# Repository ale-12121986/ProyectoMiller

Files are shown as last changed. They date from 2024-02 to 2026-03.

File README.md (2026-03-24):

## 🏭 Sistema de Automatización para Máquinas de Flexografía
📌 Descripción del Proyecto

Este proyecto consiste en el diseño y desarrollo de un sistema de automatización industrial aplicado a máquinas de impresión flexográfica.

Se implementó una arquitectura distribuida basada en microcontroladores, donde un nodo maestro coordina múltiples nodos esclavos a través de comunicación I2C, permitiendo el control independiente de cada cuerpo de impresión.

El sistema está orientado a mejorar la precisión de registro, facilitar la operación manual y garantizar la persistencia de configuraciones críticas del proceso.

## 🎯 Objetivos
Automatizar el control de múltiples cuerpos de impresión.
Mejorar la precisión en el registro de impresión.
Implementar una arquitectura escalable y robusta.
Garantizar almacenamiento persistente de parámetros operativos.
Facilitar la operación mediante interfaz manual con feedback visual.
⚙️ Arquitectura del Sistema

## El sistema se basa en un modelo Maestro–Esclavo:

Maestro (Arduino Mega 2560)
Control central del sistema
Gestión de comunicación I2C
Coordinación de los cuerpos de impresión
Esclavos (nodos independientes)
Control individual de cada cuerpo de impresión
Recepción de comandos del maestro
Ejecución de ajustes de registro
Comunicación
Protocolo: I2C (Wire Library)
Topología multi-dispositivo

## 🧠 Funcionalidades Principales
🔹 Control de Cuerpos de Impresión
Manejo independiente de hasta 6 cuerpos de impresión
Ajustes precisos en tiempo real
🔹 Control de Registro
Registro circunferencial
Registro lateral
Mejora de alineación en impresión
🔹 Persistencia de Datos
Uso de EEPROM para almacenamiento de:
Configuraciones
Parámetros de calibración
🔹 Interfaz de Usuario
Operación manual
Feedback visual para el operador
Control directo sin necesidad de sistemas externos
🔹 Hardware Personalizado

## Diseño de PCB propio
Circuitos de multiplexación optimizados

## 🧪 Tecnologías Utilizadas
Arduino Mega 2560
Comunicación I2C (Wire Library)
EEPROM
Diseño de PCB
Sistemas Embebidos
Automatización Industrial

## 🏗️ Estructura del Proyecto
/src
  ├── master/
  │     ├── main.ino
  │     └── i2c_manager.h
  │
  ├── slave/
  │     ├── slave_controller.ino
  │     └── register_control.h
  │
  ├── drivers/
  │     ├── eeprom_manager.h
  │     └── io_control.h
  │
  └── ui/
        └── manual_interface.h

/hardware
  ├── pcb_design/
  └── schematics/

/docs
  ├── architecture.md
  └── wiring_diagram.png

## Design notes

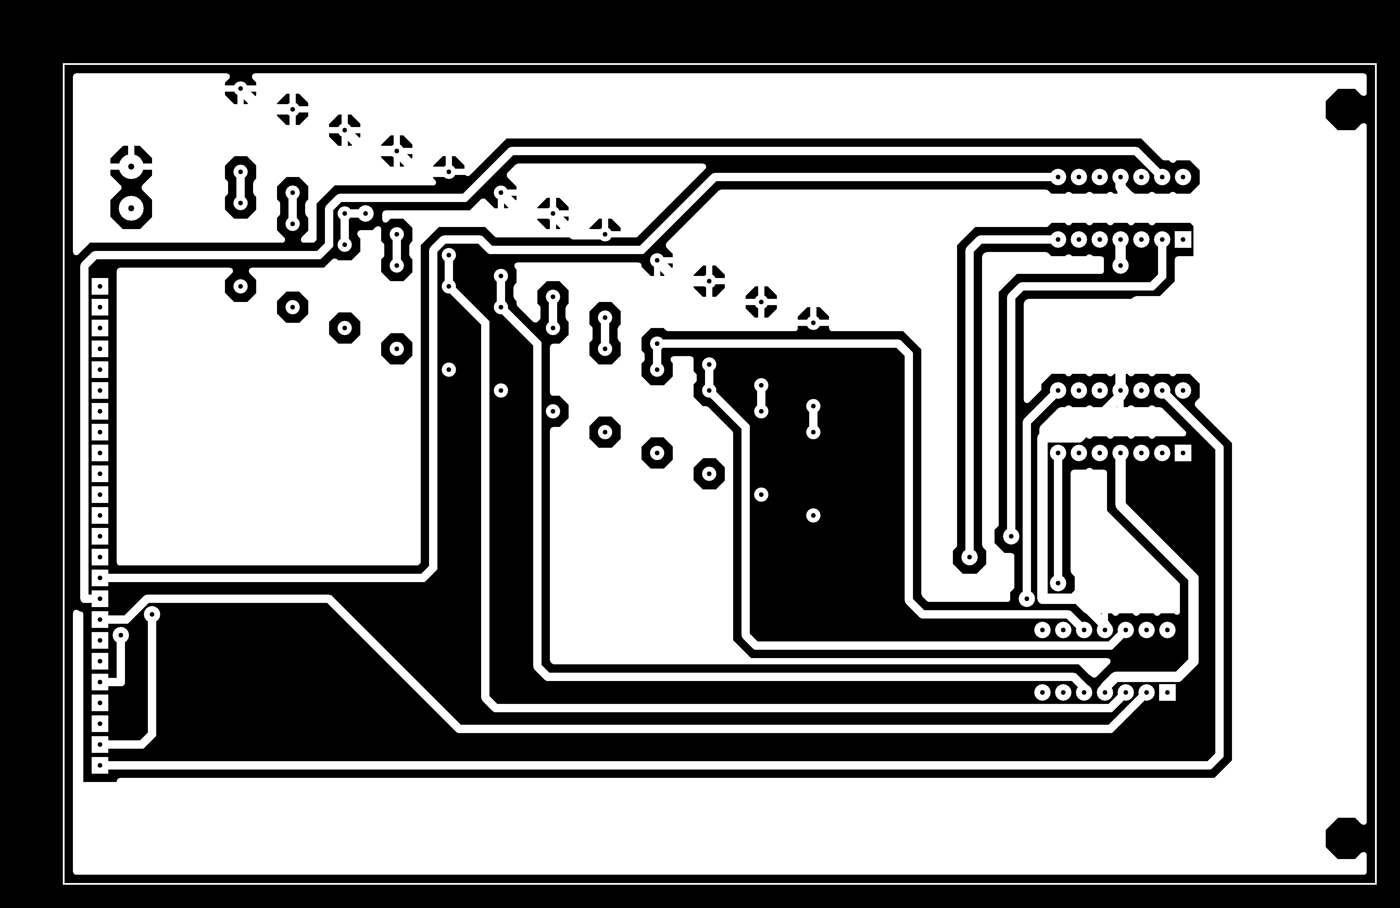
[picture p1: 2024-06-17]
pcb/PlacaBottonRegulador.bmp

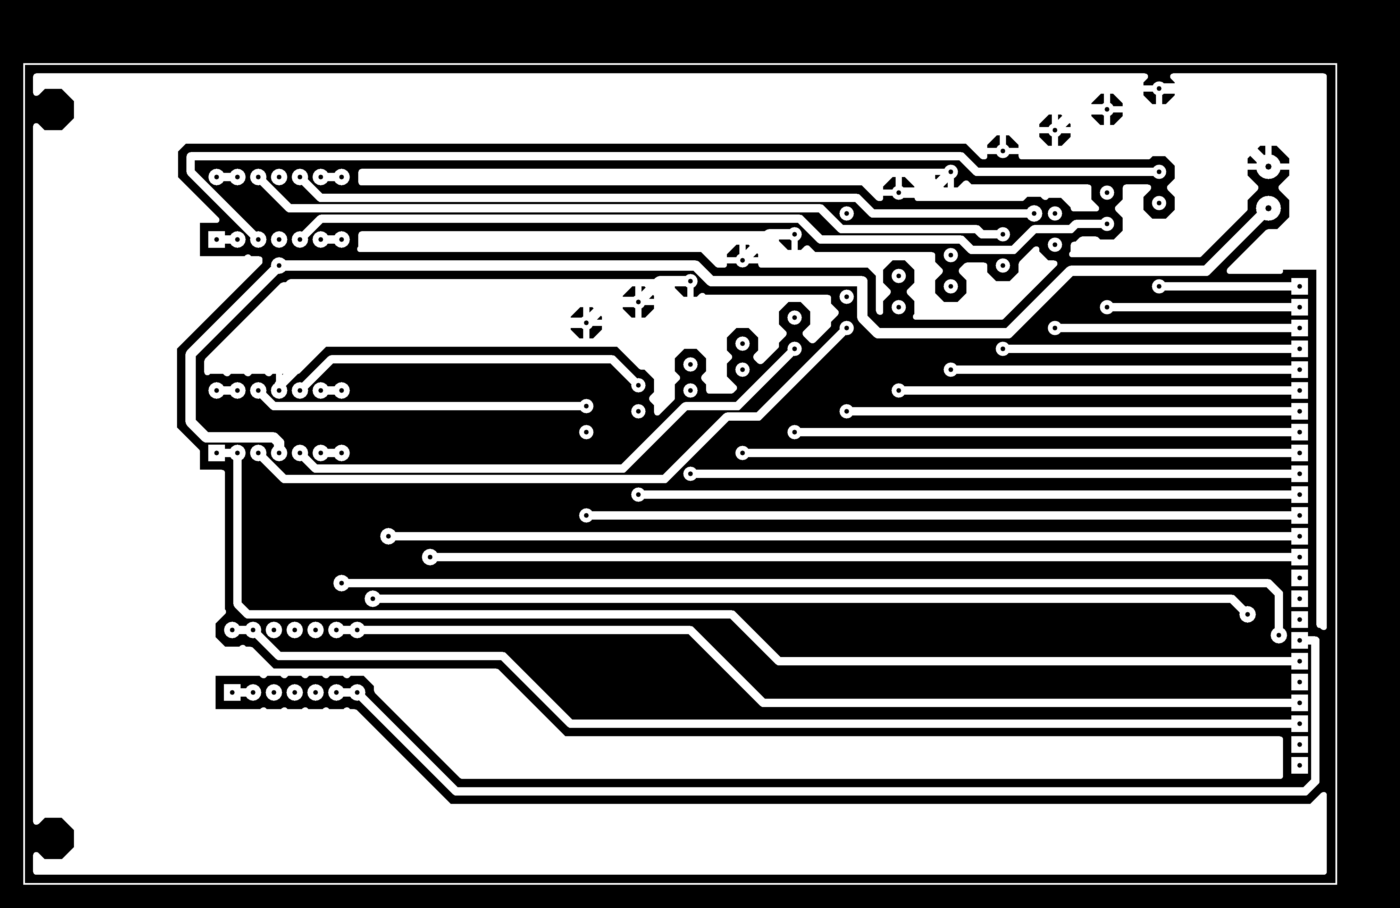
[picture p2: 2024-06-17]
pcb/PlacaTopRegulador.bmp

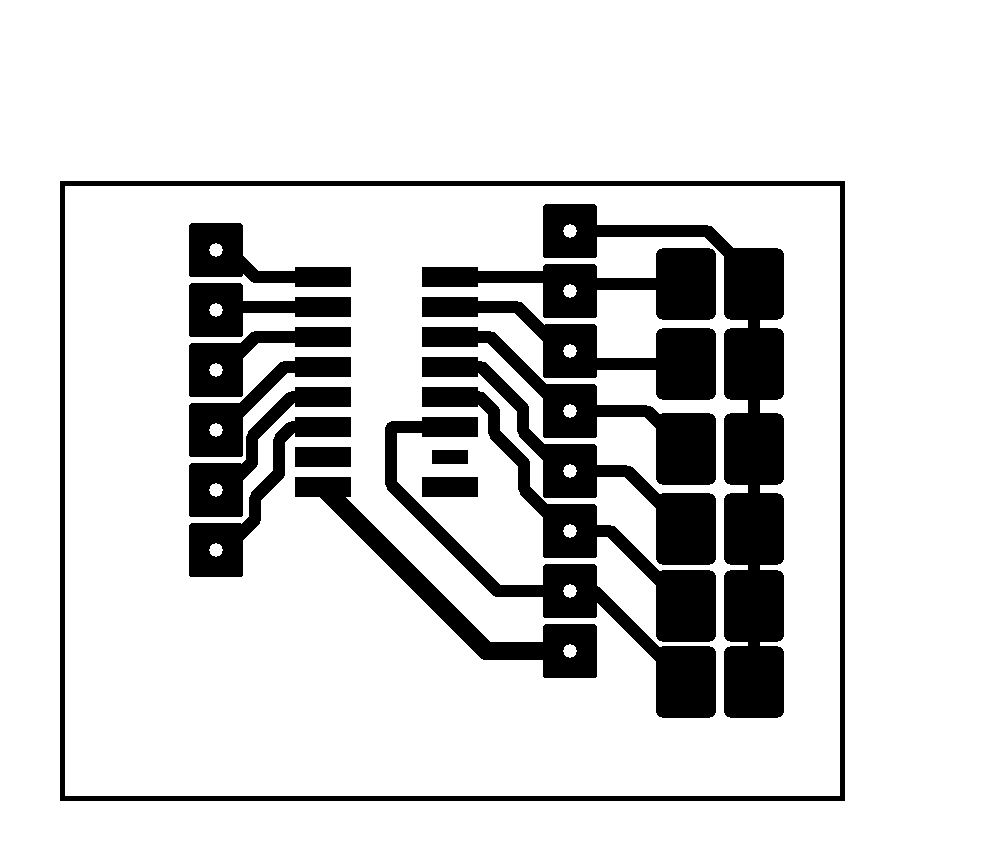
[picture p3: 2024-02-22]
pcb/driver miller.BMP

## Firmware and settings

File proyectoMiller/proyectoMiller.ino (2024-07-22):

//Maestro
#include "ControlClavija.h"
#include "DatosDisplay.h"
#include "Iluminacion.h"
#include "Direcciones.h"
#include "Registro.h"
#include "EEPROM.h"
#include <Wire.h>
#include "WString.h"
int direccionBotones = 7;
int placaClavija1, placaClavija2, placaClavija3, placaClavija4;
int clavijas = 0, cuerpos = 0, cuerpoViejo = 0, leerPotenciometro, cuerpoViejo2 = 0;
float valor1;
String valorRegistro;
int datoBarra;
int conteo = 0;
int dirBarra1 = 0, dirBarra2 = 0, dirBarra3 = 0, dirBarra4 = 0;
boolean memoria = false, trabajo = false;
int valorTinteros[6][28];
int matricesCuerpos[6][28];
const byte Boton1 = 23;  // cuerpo anterior 22
const byte Boton2 = 28;  // cuerpo1 29
const byte Boton3 = 29;  // cuerpo2 28
const byte Boton4 = 27;  // cuerpo3  26
const byte Boton5 = 22;  // cuerpo4
const byte Boton6 = 26;  // cuerpo5  27
const byte Boton7 = 24;  // cuerpo6  25
const byte Boton8 = 25;  // selecciono cambiar 24
const int pot = A2;
const int pot2 = A1;
int Centena, Decena, Unidad;
int envios = 3;
//Se llama las clases
DatosDisplay datosDisplay;
ControlClavija controlarClavija;
Direcciones direccionControl;
Iluminacion iluminacion;
Registro registro;

int ejecucionDeClavija(int posicion) {
  valor1 = analogRead(pot);
  delay(100);
  leerDato(valor1);
  Serial.println(valor1);
  datosDisplay.enviarDato(Decena, Centena, posicion);
  return valor1;
}
void enviarDatoBarra(int dato){
conteo++;
  if(conteo == 20){
    //Serial.println("se envia el dato a la barra");
    conteo = 0;
    registro.ValorBarra(dato);
    //registro.ValorBarra(dato);
  }
}
void moverRegistroC(int valor){
  retardo10ms();
  registro.moverRegistroCircunferencial(valor);
  retardo10ms();
  registro.moverRegistroCircunferencial(valor);
}

void moverRegistroL(int valor){
  retardo10ms();
  registro.moverRegistroLateral(valor);
}
void moverRegistroBarra(int valor){
  retardo10ms();
  registro.BarridoTinta(valor);
}
void cambiarCuerpo(int cuerpo){
  retardo10ms();
  registro.activarCuerpos(cuerpos);
}
void leerDato(float Valor) {
  int valor;
  valor = map(Valor, 0, 1024, 0, 1000);
  //valor = (Valor * 1000) / 1024;
  Centena = valor / 100;
  Decena = (valor - Centena * 100) / 10;
  Unidad = (valor - Centena * 100 - Decena * 10);
  datoBarra = Centena * 10 + Decena;

}
void ejecucionRegistro(String dato){  
  int negativo = 0;
  int valor = dato.toInt();
  valor = map(valor,0,1023,-150, 150);
  Centena = valor/100;
  //Decena = valor/10;
  Decena = (valor - Centena*100)/10;
  Unidad = (valor - Centena*100 - Decena*10);
  if (valor < 0) {
    negativo = 8;
    Centena = Centena*-1;
    Decena = Decena *-1;
    Unidad = Unidad *-1;    
  }
  datosDisplay.enviarDato(Unidad, Decena,1);
  retardo10ms();
  datosDisplay.enviarDato(Centena, negativo,2);
}

void barridoCuerpo(int cuerpos) {  //barre todos los cuerpos de las calvija e imprime todos los datos en los display
  //controlarClavija.posInicial();
  int i = 1;
  do {
    direccionesDeBotones();
    //Serial.print("leyendo clavija");
    //Serial.println(i);
    controlarClavija.leerPotIzquierdo(cuerpos, i);
    retardo100ms();
    leerPotenciometro = ejecucionDeClavija(4);  //va a la rutina de escribir en los display y trae el valor del potenciometro
    controlarClavija.leerPotderecho(cuerpos, i);
    retardo100ms();
    i++;
    leerPotenciometro = ejecucionDeClavija(3);
    controlarClavija.leerPotIzquierdo(cuerpos, i);
    retardo100ms();
    leerPotenciometro = ejecucionDeClavija(2);
    controlarClavija.leerPotderecho(cuerpos, i);
    retardo100ms();
    leerPotenciometro = ejecucionDeClavija(1);
    i++;
  } while (i <= 14);
}
void guardarMemoria(int cuerpos) {  //Se guarda en memoria el valor de todos los potenciometros de cada cuerpo
  int8_t dirMemoria = 0;
  for (int i = 1; i <= 14; i++) {
    controlarClavija.leerPotIzquierdo(cuerpos, i);
    retardo100ms();
    valor1 = analogRead(pot);
    EEPROM.put(dirMemoria, valor1);
    dirMemoria++;
    controlarClavija.leerPotderecho(cuerpos, i);
    retardo100ms();
    valor1 = analogRead(pot);
    EEPROM.put(dirMemoria, valor1);
    dirMemoria++;
  }
}

void compararValoresCuerpos(int cuerpos) {
  int valorPot = 0, valorMemoria = 0, dirMemoria = 0;
  for (int i = 1; i <= 14; i++) {
    EEPROM.get(dirMemoria, valorMemoria);
    controlarClavija.leerPotIzquierdo(cuerpos, i);
    retardo100ms();
    valorPot = analogRead(pot);
    while (valorPot < valorMemoria) {
      controlarClavija.motorIzquierdoMas(cuerpos, i);
    }
    while (valorPot > valorMemoria) {
      controlarClavija.motorIzquierdoMenos(cuerpos, i);
    }
    dirMemoria++;
    EEPROM.get(dirMemoria, valorMemoria);
    controlarClavija.leerPotderecho(cuerpos, i);
    retardo100ms();
    valorPot = analogRead(pot);
    while (valorPot < valorMemoria) {
      controlarClavija.motorDerechoMas(cuerpos, i);
    }
    while (valorPot > valorMemoria) {
      controlarClavija.motorDerechoMenos(cuerpos, i);
    }
    dirMemoria++;
  }
}

void direccionesDeBotones() {
  direccionBotones += 1;
  if (direccionBotones == 15) {
    direccionBotones = 8;
  }
  //Serial.print("LK");
  //Serial.println(direccionBotones);
  switch (direccionBotones) {
    case 14:
      placaClavija1 = 2;
      placaClavija2 = 2;
      placaClavija3 = 1;
      placaClavija4 = 1;
      dirBarra1 = 1;
      dirBarra2 = 2;
      dirBarra3 = 3;
      dirBarra4 = 4;
      break;
    case 13:
      placaClavija1 = 4;
      placaClavija2 = 4;
      placaClavija3 = 3;
      placaClavija4 = 3;
      dirBarra1 = 5;
      dirBarra2 = 6;
      dirBarra3 = 7;
      dirBarra4 = 8;
      break;
    case 12:
      placaClavija1 = 6;
      placaClavija2 = 6;
      placaClavija3 = 5;
      placaClavija4 = 5;
      dirBarra1 = 9;
      dirBarra2 = 10;
      dirBarra3 = 11;
      dirBarra4 = 12;
      break;
    case 11:
      placaClavija1 = 8;
      placaClavija2 = 8;
      placaClavija3 = 7;
      placaClavija4 = 7;
      dirBarra1 = 13;
      dirBarra2 = 14;
      dirBarra3 = 15;
      dirBarra4 = 16;
      break;
    case 10:
      placaClavija1 = 10;
      placaClavija2 = 10;
      placaClavija3 = 9;
      placaClavija4 = 9;
      dirBarra1 = 17;
      dirBarra2 = 18;
      dirBarra3 = 19;
      dirBarra4 = 20;
      break;
    case 9:
      placaClavija1 = 12;
      placaClavija2 = 12;
      placaClavija3 = 11;
      placaClavija4 = 11;
      dirBarra1 = 21;
      dirBarra2 = 22;
      dirBarra3 = 23;
      dirBarra4 = 24;
      break;
    case 8:
      placaClavija1 = 14;
      placaClavija2 = 14;
      placaClavija3 = 13;
      placaClavija4 = 13;
      dirBarra1 = 25;
      dirBarra2 = 26;
      dirBarra3 = 27;
      dirBarra4 = 28;
      break;
    default:
      break;
  }
  direccionControl.imprimirDireccion(direccionBotones);
}
void retardo50ms() {
  delay(50);
}
void retardo300ms() {
  delay(300);
}
void retardo10ms() {
  delay(10);
}
void retardo100ms() {
  delay(100);
}
void setup() {
  controlarClavija.configurar();
  datosDisplay.configurar();
  direccionControl.configurar();
  iluminacion.configurar();
  registro.Configurar();
  pinMode(Boton1, INPUT);
  pinMode(Boton2, INPUT);
  pinMode(Boton3, INPUT);
  pinMode(Boton4, INPUT);
  pinMode(Boton5, INPUT);
  pinMode(Boton6, INPUT);
  pinMode(Boton7, INPUT);
  pinMode(Boton8, INPUT);
  pinMode(pot, INPUT);
  //pinMode(poteDerecho,INPUT);
  //analogReference(DEFAULT);

  Serial.begin(115200);
  iluminacion.trabajoMemoria(0);
  iluminacion.encenderCuerpo(0);
  //Serial.println("Inicio Imprenta miller");
  controlarClavija.posInicial();
  delay(1000);
}
void loop() {
  // put your main code here, to run repeatedly:

Inicio:
  direccionControl.imprimirDireccion(6);  //direccion de lk6  seleccion de M1/M2
  retardo10ms();

  while (true) {  //M1: trabajo M2: memoria
    while (digitalRead(Boton6) == LOW && digitalRead(Boton7) == LOW) {
    retardo10ms();
    }
    if (digitalRead(Boton6) == HIGH) {  // Boton M1
      while (digitalRead(Boton6) == HIGH) {
        retardo10ms();
        //Serial.println("Se preciono M1 y se va a trabajo");
      }
      memoria = false;
      trabajo = true;
      iluminacion.trabajoMemoria(1);
      //Serial.println("Se preciono M1 y se va a trabajo");
      retardo300ms();
      goto Trabajar;
    }
    
    if (digitalRead(Boton7) == HIGH) {  // Boton M2
      while (digitalRead(Boton7) == HIGH) {
        retardo50ms();
      }
      trabajo = false;
      memoria = true;
      iluminacion.trabajoMemoria(2);
      //Serial.println("Se preciono M2 y se va a memoria");
      //goto Memoria;
      goto Trabajar;
    }
  }
Trabajar:
  direccionControl.imprimirDireccion(4);
  while (digitalRead(Boton1) == LOW && digitalRead(Boton2) == LOW && digitalRead(Boton3) == LOW && digitalRead(Boton4) == LOW && digitalRead(Boton5) == LOW && digitalRead(Boton6) == LOW && digitalRead(Boton7) == LOW && digitalRead(Boton8) == LOW) {
    retardo50ms();
  }
trabajoCuerpo:
  direccionControl.imprimirDireccion(4);
  //direccionControl.imprimirDireccion(4);// Direccion de las placas de seleccionar cuerpo
  if (digitalRead(Boton1) == HIGH) {
    iluminacion.encenderCuerpo(7);
    //Serial.println("Se selecciono el cuerpo anterior");
    cuerpoViejo2 = cuerpos;
    cuerpos = cuerpoViejo;
    iluminacion.encenderCuerpo(cuerpos);
    registro.activarCuerpos(cuerpos);
    while (digitalRead(Boton1) == HIGH) {
      retardo100ms();
    }
    iluminacion.encenderCuerpo(9);
    //registro.activarCuerpos(cuerpos);
    cuerpoViejo = cuerpoViejo2;
    if (trabajo == true) {
      barridoCuerpo(cuerpos);
    }
  }

  if (digitalRead(Boton2) == HIGH) {
    //Serial.println("Se selecciono el cuerpo1");
    cuerpoViejo = cuerpos;
    cuerpos = 1;
    //registro.activarCuerpos(cuerpos);
    iluminacion.encenderCuerpo(cuerpos);
    while (digitalRead(Boton2) == HIGH) {
      retardo100ms();
    }
    cambiarCuerpo(cuerpos);
    iluminacion.encenderCuerpo(cuerpos);
    if (trabajo == true) {
      barridoCuerpo(cuerpos);
    }

  } else if (digitalRead(Boton3) == HIGH) {
    //Serial.println("Se selecciono el cuerpo2");
    cuerpoViejo = cuerpos;
    cuerpos = 2;
    //registro.activarCuerpos(cuerpos);
    iluminacion.encenderCuerpo(cuerpos);
    while (digitalRead(Boton3) == HIGH) {
      retardo100ms();
    }
    cambiarCuerpo(cuerpos);
    iluminacion.encenderCuerpo(cuerpos);
    if (trabajo == true) {
      barridoCuerpo(cuerpos);
    }

  } else if (digitalRead(Boton4) == HIGH) {
    //Serial.println("Se selecciono el cuerpo3");
    cuerpoViejo = cuerpos;
    cuerpos = 3;
    iluminacion.encenderCuerpo(cuerpos);
    while (digitalRead(Boton4) == HIGH) {
      retardo100ms();
    }
    cambiarCuerpo(cuerpos);
    iluminacion.encenderCuerpo(cuerpos);
    if (trabajo == true) {
      barridoCuerpo(cuerpos);
    }

  } else if (digitalRead(Boton5) == HIGH) {
    //Serial.println("Se selecciono el cuerpo4");
    cuerpoViejo = cuerpos;
    cuerpos = 4;
    iluminacion.encenderCuerpo(cuerpos);
    while (digitalRead(Boton5) == HIGH) {
      retardo100ms();
    }
    cambiarCuerpo(cuerpos);
    iluminacion.encenderCuerpo(cuerpos);
    if (trabajo == true) {
      barridoCuerpo(cuerpos);
    }

  } else if (digitalRead(Boton6) == HIGH) {
    //Serial.println("Se selecciono el cuerpo5");
    cuerpoViejo = cuerpos;
    cuerpos = 5;
    iluminacion.encenderCuerpo(cuerpos);
    while (digitalRead(Boton6) == HIGH) {
      retardo100ms();
    }
    cambiarCuerpo(cuerpos);
    iluminacion.encenderCuerpo(cuerpos);
    barridoCuerpo(cuerpos);

  } else if (digitalRead(Boton7) == HIGH) {
    cuerpoViejo = cuerpos;
    cuerpos = 6;
    iluminacion.encenderCuerpo(cuerpos);
    //Serial.println("Se selecciono el cuerpo6");
    while (digitalRead(Boton7) == HIGH) {
      retardo100ms();
    }
    cambiarCuerpo(cuerpos);
    iluminacion.encenderCuerpo(cuerpos);
    if (trabajo == true) {
      barridoCuerpo(cuerpos);
    }
    if(memoria == true ){
      barridoCuerpo(cuerpos);
      goto Memoria;
    }
  } else if (digitalRead(Boton8) == HIGH) {
    //cuerpos = 90;
    //posCuerpo = 6;
    //Serial.println("Se selecciono cambiar");
    while (digitalRead(Boton8) == HIGH) {
      retardo100ms();
      
    }
    //goto Inicio;
  }
  if (trabajo == true) {
    goto Tinteros;
  }
Tinteros:
  direccionesDeBotones();  // direcciones de las clavijas
  delay(20);

  if (digitalRead(Boton7) == HIGH) {  //motor izquierdo que gira derecha
    controlarClavija.posInicial();
    direccionControl.imprimirLaDireccion();
    Serial.println("Boton 7(Boton izquierdo +)");
    controlarClavija.motorIzquierdoMenos(cuerpos, placaClavija1);
    for (int i = 0; i < 2; i++) {
      //registro.DireccionBarra(dirBarra1);
    }
    while (digitalRead(Boton7) == HIGH) {
      
      leerPotenciometro = ejecucionDeClavija(4);  //va a la rutina de escribir en los display y trae el valor del potenciometro
      //enviarDatoBarra(datoBarra);
      if (leerPotenciometro >= 900) {
        controlarClavija.resetflipflop();
      }
    }
    controlarClavija.resetflipflop();
    retardo10ms();
  }

  if (digitalRead(Boton1) == HIGH) {  //motor izquierdo que gira izquierda
    controlarClavija.posInicial();
    direccionControl.imprimirLaDireccion();
    Serial.println("Boton 1(Boton izquierdo -)");
    controlarClavija.motorIzquierdoMas(cuerpos, placaClavija1);
    for (int i = 0; i < 2; i++) {
      //registro.DireccionBarra(dirBarra1);
    }
    while (digitalRead(Boton1) == HIGH) {
      
      leerPotenciometro = ejecucionDeClavija(4);  //va a la rutina de escribir en los display y trae el valor del potenciometro
      //enviarDatoBarra(datoBarra);
      if (leerPotenciometro <= 100) {
        controlarClavija.resetflipflop();
      }
    }
    controlarClavija.resetflipflop();
    retardo10ms();
  }

  if (digitalRead(Boton2) == HIGH) {  //motor derecho que gira derecha
    controlarClavija.posInicial();
    direccionControl.imprimirLaDireccion();
    Serial.println("Boton 2(Boton Boton Derecho +)");
    controlarClavija.motorDerechoMenos(cuerpos, placaClavija2);
    for (int i = 0; i < 2; i++) {
      //registro.DireccionBarra(dirBarra2);
    }
    while (digitalRead(Boton2) == HIGH) {
  
      leerPotenciometro = ejecucionDeClavija(3);  //va a la rutina de escribir en los display y trae el valor del potenciometro
      //enviarDatoBarra(datoBarra);
      if (leerPotenciometro >= 900) {
        controlarClavija.resetflipflop();
      }
    }
    controlarClavija.resetflipflop();
    retardo10ms();
  }

  if (digitalRead(Boton6) == HIGH) {  //motor derecho que gira izquierda
    controlarClavija.posInicial();
    direccionControl.imprimirLaDireccion();
    Serial.println("Boton 6(Boton Derecho -)");
    controlarClavija.motorDerechoMas(cuerpos, placaClavija2);
    for (int i = 0; i < 2; i++) {
      //registro.DireccionBarra(dirBarra2);
    }
    while (digitalRead(Boton6) == HIGH) {
    
      leerPotenciometro = ejecucionDeClavija(3);  //va a la rutina de escribir en los display y trae el valor del potenciometro
      //enviarDatoBarra(datoBarra);
      if (leerPotenciometro <= 100) {
        controlarClavija.resetflipflop();
      }
    }
    controlarClavija.resetflipflop();
    retardo10ms();
  }

  if (digitalRead(Boton4) == HIGH) {  //motor izquierdo que girai derecha
    controlarClavija.posInicial();
    direccionControl.imprimirLaDireccion();
    Serial.println("Boton 4(Boton izquierdo +)");
    controlarClavija.motorIzquierdoMenos(cuerpos, placaClavija3);
    for (int i = 0; i < 2; i++) {
      //registro.DireccionBarra(dirBarra3);
    }
    while (digitalRead(Boton4) == HIGH) {
      leerPotenciometro = ejecucionDeClavija(2);  //va a la rutina de escribir en los display y trae el valor del potenciometro
      //enviarDatoBarra(datoBarra);
      if (leerPotenciometro >= 900) {
        controlarClavija.resetflipflop();
      }
    }
    controlarClavija.resetflipflop();
    retardo50ms();
  }

  if (digitalRead(Boton3) == HIGH) {  //motor izquierdo que gira izquierda
    controlarClavija.posInicial();
    direccionControl.imprimirLaDireccion();
    Serial.println("Boton 3(Boton izquierdo -)");
    controlarClavija.motorIzquierdoMas(cuerpos, placaClavija3);
    for (int i = 0; i < 2; i++) {
      //registro.DireccionBarra(dirBarra3);
    }
    while (digitalRead(Boton3) == HIGH) {
      
      leerPotenciometro = ejecucionDeClavija(2);
      //enviarDatoBarra(datoBarra);
      if (leerPotenciometro <= 100) {
        controlarClavija.resetflipflop();
      }
    }
    controlarClavija.resetflipflop();
    retardo10ms();
  }

  if (digitalRead(Boton8) == HIGH) {  //motor derecho que gira derecha
    controlarClavija.posInicial();
    direccionControl.imprimirLaDireccion();
    Serial.println("Boton 8(Boton Boton Derecho +)");
    controlarClavija.motorDerechoMenos(cuerpos, placaClavija4);
    for (int i = 0; i < 2; i++) {
      //registro.DireccionBarra(dirBarra4);
    }
    while (digitalRead(Boton8) == HIGH) {
    
      leerPotenciometro = ejecucionDeClavija(1);  //va a la rutina de escribir en los display y trae el valor del potenciometro
      //enviarDatoBarra(datoBarra);
      if (leerPotenciometro >= 900) {
        controlarClavija.resetflipflop();
      }
    }
    controlarClavija.resetflipflop();
    retardo10ms();
  }

  if (digitalRead(Boton5) == HIGH) {  //motor derecho que gira izquierda
    controlarClavija.posInicial();
    direccionControl.imprimirLaDireccion();
    Serial.println("Boton 5(Boton Derecho -)");
    controlarClavija.motorDerechoMas(cuerpos, placaClavija4);
    for (int i = 0; i < 2; i++) {
      //registro.DireccionBarra(dirBarra4);
    }
    while (digitalRead(Boton5) == HIGH) {
      leerPotenciometro = ejecucionDeClavija(1);  //va a la rutina de escribir en los display y trae el valor del potenciometro
      //enviarDatoBarra(datoBarra);
      if (leerPotenciometro <= 100) {
        //Serial.print("entro en proteccion");
        controlarClavija.resetflipflop();
      }
    }
    controlarClavija.resetflipflop();
    retardo10ms();
  }
  direccionControl.imprimirDireccion(4);  //cambiar de cuerpo
  if (digitalRead(Boton1) == HIGH && digitalRead(Boton2) == HIGH && digitalRead(Boton3) == HIGH && digitalRead(Boton4) == HIGH && digitalRead(Boton5) == HIGH && digitalRead(Boton6) == HIGH && digitalRead(Boton7) == HIGH && digitalRead(Boton8) == HIGH) {
    retardo50ms();
    goto Trabajar;
    //goto trabajoCuerpo;
  }

  direccionControl.imprimirDireccion(6);  //direccion de lk6  seleccion de M1/M2
  if (digitalRead(Boton6) == HIGH || digitalRead(Boton7) == HIGH) {
    goto Inicio;
  }
  if(digitalRead(Boton2) == HIGH){    //Boton menos mutual stting module 
    //Serial.println("Boton 2(Boton Boton + mutual stting module)");
    moverRegistroBarra(2);
    while (digitalRead(Boton2) == HIGH) {
      retardo50ms();
      //leerPotenciometro = ejecucionDeClavija(2);
    }
    moverRegistroBarra(4);
  }
  if(digitalRead(Boton1) == HIGH){    //Boton menos mutual stting module 
    //Serial.println("Boton 1(Boton Boton - mutual stting module)");
    moverRegistroBarra(3);
    while (digitalRead(Boton1) == HIGH) {
      retardo50ms();
      //leerPotenciometro = ejecucionDeClavija(2);
    }
    moverRegistroBarra(4);
  }

  //---------------Registro circunferencial-------------------------
  direccionControl.imprimirDireccion(2);  //Diereccion para registro circunferencial
    
    if(digitalRead(Boton5) == LOW){  //incrementar
      //Serial.println("Se activa el Registro circunferencial mas");
      moverRegistroC(2);
      while(digitalRead(Boton5) == LOW){
        retardo50ms();
        valorRegistro = registro.leerTransmisor();
        retardo100ms();
        ejecucionRegistro(valorRegistro);
        if (valorRegistro.toInt() > 800) {
          moverRegistroC(4);
          moverRegistroC(4);
        }
      }
      moverRegistroC(4);
    }
    
    if(digitalRead(Boton1) == LOW){  //decrementar
      //Serial.println("Se activa el registro circunferencial menos");
      moverRegistroC(3);
      while(digitalRead(Boton1) == LOW){
        retardo50ms();
        valorRegistro = registro.leerTransmisor();
        retardo100ms();
        ejecucionRegistro(valorRegistro);
        if (valorRegistro.toInt() < 120) {
          moverRegistroC(4);
          delay(1);
          moverRegistroC(4);
        }
      }
      moverRegistroC(4);
      delay(1);
      moverRegistroC(4);
    }
    if(digitalRead(Boton8) == LOW){  //centrar
      //Serial.println("Se activa el registro circunferencial centrar");
      moverRegistroC(1);
      while(digitalRead(Boton8) == LOW){
        retardo50ms();
        valorRegistro = registro.leerTransmisor();
        ejecucionRegistro(valorRegistro);
      }
      moverRegistroC(4);
      delay(1);
      moverRegistroC(4);
    }
  // -------------------Registro lateral-----------------------------   
  direccionControl.imprimirDireccion(3);  //Diereccion para registro lateral
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

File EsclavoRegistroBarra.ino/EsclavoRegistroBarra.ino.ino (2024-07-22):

#include "Cuerpo.h"
#include "RegistroCircunferencial.h"
#include "RegistroLateral.h"
#include "BarraGraf.h"
#include "BarridoTinta.h"
#include <Wire.h>
#include "WString.h"
byte nDato = 0;
char cadena[5];
String prueba; 
char leerTransmisorCircunferencial[] = "TransmisorC";
char leerTransmisorLateral[] = "TransmisorL"; 
char dato;
int cuerpo, contador = 0;
int valorTransmisor;
bool bandera = false ;
String variable2  = "";
bool acRegCir = false, acRegLat = false, acBar= false;
Cuerpo claseCuerpo;
RegistroCircunferencial registroCircunferencial;
RegistroLateral registroLateral;
BarraGraf barraGRaf;
BarridoTinta barridoTinta;
void requestEvent() {
  contador++;
  if (contador == 2) {
    Wire.print(variable2);
    contador = 0;      
  }
  if (contador == 1) {
    if (acRegCir == true) { //entro a leer los valores del registro circunferencial
      valorTransmisor = registroCircunferencial.leerPotenciometro(claseCuerpo.cuerpo());
      //Serial.println("envio el dato circunferencial");
    }
    if (acRegLat == true) { //entro a leer los valores del registro lateral
      valorTransmisor = registroLateral.leerPotenciometro(claseCuerpo.cuerpo());
      //Serial.println("envio el dato lateral");
    }    
    int valor = valorTransmisor;
    variable2 = String(valor);
    Serial.println(valorTransmisor);  
    Wire.write(int(variable2.length())); // respond with message of 6 bytes para que funcione tiene q enviar un dato int con la guncion write
    Serial.println(variable2.length());
  }  

  //Serial.println("Dato enviado");
}
void recibeDato(int howMany){
  //Serial.println("entro en sub rutina");
  nDato = 0;
  dato = '\0';  // Esto vacía el contenido de dato
  strcpy(cadena, "");
  while (Wire.available()) {
    dato = Wire.read();
    Serial.print(dato);
    cadena[nDato] = dato;
    nDato++;
    if(strcmp(cadena,"Cue1") == 0){ 
      prueba = "CUER1";
    }
    if(strcmp(cadena,"Cue2") == 0){ 
      prueba = "CUER2";
    }
    if(strcmp(cadena,"Cue3") == 0){ 
      prueba = "CUER3";
    }
    if(strcmp(cadena,"Cue4") == 0){ 
      prueba = "CUER4";
    }
    if(strcmp(cadena,"Cue5") == 0){ 
      prueba = "CUER5";
    }
    if(strcmp(cadena,"Cue6") == 0){ 
      
      prueba = "CUER6";
    } 
    if(strcmp(cadena,"cir1") == 0){
      prueba = "REGC1";
    }
    if(strcmp(cadena,"cir2") == 0){
      prueba = "REGC2";
    }
    if(strcmp(cadena,"cir3") == 0){
      prueba = "REGC3";
    }
    if(strcmp(cadena,"cir4") == 0){
      prueba = "REGC4";
    }
    if(strcmp(cadena,"lat1") == 0){
      prueba = "REGL1";
    }
    if(strcmp(cadena,"lat2") == 0){
      prueba = "REGL2";
    }
    if(strcmp(cadena,"lat3") == 0){
      prueba = "REGL3";
    }
    if(strcmp(cadena,"lat0") == 0){
      prueba = "REGL0";
    }
    if(strcmp(cadena,"bgf") == 0){
      prueba = "BGF";
    }
    if(strcmp(cadena,"bgv") == 0){
      prueba = "BGV";
    }
    if(strcmp(cadena,"bbt1") == 0){
      prueba = "BBT1";
    }
    if(strcmp(cadena,"bbt2") == 0){
      prueba = "BBT2";
    }
    if(strcmp(cadena,"bbt3") == 0){
      prueba = "BBT3";
    }
    if(strcmp(cadena,"bbt4") == 0){
      prueba = "BBT4";
    }
  }
  strcpy(cadena, "");
  bandera = true;
}
void setup() {
  // put your  setup code here, to run once:
  claseCuerpo.configurar();
  registroCircunferencial.configurar();
  registroLateral.configurar();
  barraGRaf.configurar();
  Serial.begin(115200);
  Wire.begin(2);
  Wire.onReceive(recibeDato);
  Wire.onRequest(requestEvent); // register event
  claseCuerpo.seleccionarCuerpo(0);
  Serial.println( "Esclavo esclavo");
  registroCircunferencial.moverRegistro(4);
  registroLateral.moverRegistro(0);
  }

void loop() {
  // put your main code here, to run repeatedly:
  if (bandera) {
    if (prueba.equals("CUER1")) {
      bandera = false;
      cuerpo = 1;
      claseCuerpo.seleccionarCuerpo(1);
      delay(10);

    }
    if (prueba.equals("CUER2")) {
      bandera = false;
      cuerpo = 2;
      claseCuerpo.seleccionarCuerpo(2);
      delay(10);
    }
    if (prueba.equals("CUER3")) {
      bandera = false;
      cuerpo = 3;
      claseCuerpo.seleccionarCuerpo(3);
      delay(10);
    }
    if (prueba.equals("CUER4")) {
      bandera = false;
      cuerpo = 4;
      claseCuerpo.seleccionarCuerpo(4);
      delay(10);
    }
    if (prueba.equals("CUER5")) {
      bandera = false;
      cuerpo = 5;
      claseCuerpo.seleccionarCuerpo(5);
      delay(10);
    }
    if (prueba.equals("CUER6")) {
      bandera = false;
      cuerpo = 6;
      claseCuerpo.seleccionarCuerpo(6);
      delay(10);
    }
    if (prueba.equals("REGC1")) {
      Serial.println("entro en registro circunferencial 1"); 
      acRegCir = true;  //leer valores del registro circunferencial activado
      acRegLat = false; //leer valores del registro lateral desactivado
      bandera = false;
      //registroCircunferencial.cuerpo(cuerpo);
      registroCircunferencial.moverRegistro(1);
    }
    if (prueba.equals("REGC2")) {
      Serial.println("entro en registro circunferencial 2"); 
      acRegCir = true;  //leer valores del registro circunferencial activado
      acRegLat = false; //leer valores del registro lateral desactivado
      bandera = false;
      //registroCircunferencial.cuerpo(cuerpo);
      registroCircunferencial.moverRegistro(2);
    }
    if (prueba.equals("REGC3")) {
      Serial.println("entro en registro circunferencial 3"); 
      acRegCir = true;  //leer valores del registro circunferencial activado
      acRegLat = false; //leer valores del registro lateral desactivado
      bandera = false;
      //registroCircunferencial.cuerpo(cuerpo);
      registroCircunferencial.moverRegistro(3);
    }
    if (prueba.equals("REGC4")) {
      Serial.println("entro en registro circunferencial 4"); 
      acRegCir = true;  //leer valores del registro circunferencial activado
      acRegLat = false; //leer valores del registro lateral desactivado
      bandera = false;
      //registroCircunferencial.cuerpo(cuerpo);
      registroCircunferencial.moverRegistro(4);
    }
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

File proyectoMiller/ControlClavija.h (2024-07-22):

//#include "HardwareSerial.h"
#include "pins_arduino.h"
#include "Arduino.h"

class ControlClavija{
  private:
                     // placa interface 
  const byte a = A7; //8
  const byte b = A11;//4
  const byte c = A9; //6
  const byte d = A8; //7
  const byte e = A12;//3
  const byte f = A13;//2
  const byte g = A10;//5
  const byte h = A14;//1
  const byte i = A5; //10
  const byte j = A3; //12
  const byte k = A6; //9
  const byte l = A4; //11
  int direccion;
  int selecMotor;                      // Direccionde las clavijas 
  int N = 7;                           //1,2,3,4,5,6,7 
  int dirclavijas[7] ={e,f,b,g,c,d,a}; //e,f,a,g,c,d,b
  const int clavijas[6][15][7] = {
//             0               1               2               3               4               5               6               7               8               9              10              11              12              13              14
//         1 2 3 4 5 6 7   1 2 3 4 5 6 7   1 2 3 4 5 6 7   1 2 3 4 5 6 7   1 2 3 4 5 6 7   1 2 3 4 5 6 7   1 2 3 4 5 6 7   1 2 3 4 5 6 7   1 2 3 4 5 6 7   1 2 3 4 5 6 7   1 2 3 4 5 6 7   1 2 3 4 5 6 7   1 2 3 4 5 6 7   1 2 3 4 5 6 7   1 2 3 4 5 6 7 
/*1 0*/  {{1,1,1,1,0,1,1},{1,0,1,1,0,1,1},{0,1,1,1,0,1,1},{0,0,1,1,0,1,1},{1,1,0,1,0,1,1},{1,0,0,1,0,1,1},{0,1,0,1,0,1,1},{0,0,0,1,0,1,1},{1,1,1,0,0,1,1},{1,0,1,0,0,1,1},{0,1,1,0,0,1,1},{0,0,1,0,0,1,1},{1,1,0,0,0,1,1},{1,0,0,0,0,1,1},{0,1,0,0,0,1,1}},
/*2 1*/  {{1,1,1,1,1,0,1},{1,0,1,1,1,0,1},{0,1,1,1,1,0,1},{0,0,1,1,1,0,1},{1,1,0,1,1,0,1},{1,0,0,1,1,0,1},{0,1,0,1,1,0,1},{0,0,0,1,1,0,1},{1,1,1,0,1,0,1},{1,0,1,0,1,0,1},{0,1,1,0,1,0,1},{0,0,1,0,1,0,1},{1,1,0,0,1,0,1},{1,0,0,0,1,0,1},{0,1,0,0,1,0,1}},
/*3 2*/  {{1,1,1,1,0,0,1},{1,0,1,1,0,0,1},{0,1,1,1,0,0,1},{0,0,1,1,0,0,1},{1,1,0,1,0,0,1},{1,0,0,1,0,0,1},{0,1,0,1,0,0,1},{0,0,0,1,0,0,1},{1,1,1,0,0,0,1},{1,0,1,0,0,0,1},{0,1,1,0,0,0,1},{0,0,1,0,0,0,1},{1,1,0,0,0,0,1},{1,0,0,0,0,0,1},{0,1,0,0,0,0,1}},
/*4 3*/  {{1,1,1,1,1,1,0},{1,0,1,1,1,1,0},{0,1,1,1,1,1,0},{0,0,1,1,1,1,0},{1,1,0,1,1,1,0},{1,0,0,1,1,1,0},{0,1,0,1,1,1,0},{0,0,0,1,1,1,0},{1,1,1,0,1,1,0},{1,0,1,0,1,1,0},{0,1,1,0,1,1,0},{0,0,1,0,1,1,0},{1,1,0,0,1,1,0},{1,0,0,0,1,1,0},{0,1,0,0,1,1,0}},
/*5 4*/  {{1,1,1,1,0,1,0},{1,0,1,1,0,1,0},{0,1,1,1,0,1,0},{0,0,1,1,0,1,0},{1,1,0,1,0,1,0},{1,0,0,1,0,1,0},{0,1,0,1,0,1,0},{0,0,0,1,0,1,0},{1,1,1,0,0,1,0},{1,0,1,0,0,1,0},{0,1,1,0,0,1,0},{0,0,1,0,0,1,0},{1,1,0,0,0,1,0},{1,0,0,0,0,1,0},{0,1,0,0,0,1,0}},
/*6 5*/  {{1,1,1,1,1,0,0},{1,0,1,1,1,0,0},{0,1,1,1,1,0,0},{0,0,1,1,1,0,0},{1,1,0,1,1,0,0},{1,0,0,1,1,0,0},{0,1,0,1,1,0,0},{0,0,0,1,1,0,0},{1,1,1,0,1,0,0},{1,0,1,0,1,0,0},{0,1,1,0,1,0,0},{0,0,1,0,1,0,0},{1,1,0,0,1,0,0},{1,0,0,0,1,0,0},{0,1,0,0,1,0,0}},
};
  void imprimirDirClavija(int cuerpo, int placa){
    //Serial.print("cuerpo: ");
    // Serial.println(cuerpo);
    // Serial.print("placa: ");
    // Serial.println(placa); 
    // Serial.println(" ");    
    for (int i=0; i<N; i++){
      digitalWrite(dirclavijas[i], clavijas[cuerpo-1][placa][i]);
      //Serial.print(clavijas[cuerpo-1][placa][i]);     
    }
    delay(1);
  }
  
  public:

  void configurar(){
    pinMode(i, OUTPUT);
    pinMode(k, OUTPUT);
    pinMode(j, OUTPUT);
    pinMode(l, OUTPUT);
    pinMode(h, OUTPUT);
    //DDRK = B11111111;
    pinMode(a, OUTPUT);
    pinMode(b, OUTPUT);
    pinMode(c, OUTPUT);
    pinMode(d, OUTPUT);
    pinMode(e, OUTPUT);  
    pinMode(f, OUTPUT);
    pinMode(g, OUTPUT);
  }

  void posInicial(){
    digitalWrite(j, LOW);//HIGH
  }
  
  void motorIzquierdoMas(int cuerpo, int placa){
    imprimirDirClavija(cuerpo, placa);
    digitalWrite(h, LOW);// HIGH
    digitalWrite(j, HIGH);//LOW
    digitalWrite(i, LOW);//HIGH
    digitalWrite(k, HIGH);//LOW
    digitalWrite(l, LOW);//HIGH
    delay(25);
    digitalWrite(l, HIGH);//LOW  
  }
  void motorIzquierdoMenos(int cuerpo, int placa){    
    imprimirDirClavija(cuerpo, placa);
    digitalWrite(h, LOW);//HIGH
    digitalWrite(j, HIGH);//LOW
    digitalWrite(i, HIGH);//LOW
    digitalWrite(k, LOW);//HIGH
    digitalWrite(l, LOW);//HIGH
    delay(25);
    digitalWrite(l, HIGH);//LOW
  }
  void motorDerechoMas(int cuerpo, int placa){
    imprimirDirClavija(cuerpo, placa);
    digitalWrite(h, HIGH);//LOW
    digitalWrite(j, HIGH);//LOW
    digitalWrite(i, LOW);//HIGH
    digitalWrite(k, HIGH);//LOW
    digitalWrite(l, LOW);//HIGH
    delay(25);
    digitalWrite(l, HIGH);//LOW  
  }
  void motorDerechoMenos(int cuerpo ,int placa){
    imprimirDirClavija(cuerpo, placa);
    digitalWrite(h, HIGH);//LOW
    digitalWrite(j, HIGH);//LOW
    digitalWrite(i, HIGH);//LOW
    digitalWrite(k, LOW);//HIGH
    digitalWrite(l, LOW);//HIGH
    delay(25);
    digitalWrite(l, HIGH);//LOW
  }
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

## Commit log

2023-01-02 Se creo la memoria
    Se crean las subrutinas de memoria para guardar en memoria los valores de los tinteros set el valor de los tinteros de un cuerpo a otro
2023-01-05 modificacion de subir y bajar tintero
    Se modifico el girar motor izquierdo y derecho, se cambiaran para que trabaje en realicion con los tinteros
2023-01-05 Modificcion de retardo
    Se acortaron todos los retardos
2023-01-05 configuracion de barrido de pot
    Se modifico la conversion para el barrido de por, al seleccionar cuerpo realiza barrido de cuerpo
2023-01-13 Prueba pullup
    Se realizo la modificación de la conexión a pullup para octocoplar las entradas y los pines van a estar en bajo
2023-01-15 Modificacion por fallas en el original
    No estaba funcionando y se procedió a ir a una versión anterior con modificación en la iluminación
2023-02-25 programación de la comunicación I2C
    Se realizo la comunicación entre el maestro y el esclavo la información que se envía al segundo Arduino mega va para activar el modulo de relé y el modulo de led del panel de trabajo
2023-03-10 Se programo registro circunferencial
    Se programo la opción para incrementar y decrementar el registro circunferencial a diferencia de las demás opciones de botones, estos se actúan en bajo el botón 5 el botón 1 y el botón 8
2023-03-26 Programacion de barra graph
    Se programo la barra de led con la matriz de direcciones y la matriz de encendido de los leds
2023-03-26 actualizar por fallas
    Se actualizo por problemas
    [DatosDisplay.h, proyectoMiller.ino]
2023-04-29 eliminar carpetas que no se utilizan
2023-04-29 modificación de carpetas e información
2023-04-29 modifico entradas de registro
    Se cambio la entrada de registro circunferencial las entradas son 1 para-, 5 para mas y 8 para centro
2023-06-10 barra graf
    Se programo la barra de leds
2023-06-10 barra graf
    se arreglaron las direcciones de la barra de leds
    [BarraGraf.h]
2023-07-09 programacion de regirstro circunferencial, lateira y el barra graf
    Se programo el registro circunferencial y lateral, con los displays y la lectura del potenciometro, el envio por protocola i2c al maestrio, se programo el envio de los potenciometros de las clavijas 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
    [Conexion de los pines de maestro.xlsx]
2023-07-21 modificacion tinteros
    Se modifico la salida de los tinteros ya se que se colocaron drivers de salida y
2023-07-29 modificacion de de la matriz de tintero
    Se modifico la matriz del tintero , ya que se coloco driver unl2803
2023-08-13 maodificacion de lectura de adc
    se modifico la forma como va a leer el adc del esclavo
    [Conexion de los pines de maestro.xlsx]
2023-10-05 diseño de pcb
    se diseñaron las 2 pcb
    [PlacaMaestro2 - CADCAM Bottom Assembly.GBR, PlacaMaestro2 - CADCAM Bottom Copper.GBR, PlacaMaestro2 - CADCAM Bottom Silk Screen.GBR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]
2023-10-10 modificacion de la pcb
2024-02-22 modificación de las salidas al multiplexor
2024-02-24 modificacion en envio de datos de i2c
    se modifico colocando mensaje para entender el codigo
2024-02-24 se elimina la modificacion antetior
2024-04-19 modificaciones en la selección de cuerpos
2024-05-24 modificación del pcb
2024-05-27 Se genera la pcb para mandar a fabricar a china
    [PlacaMaestro2 - CADCAM Bottom Assembly.GBR, PlacaMaestro2 - CADCAM Bottom Copper.GBR, PlacaMaestro2 - CADCAM Bottom Solder Resist.GBR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]
2024-05-27 se diseño la gerber de la placa esclavo
    [Proyecto_PCB - CADCAM Bottom Assembly.GBR, Proyecto_PCB - CADCAM Bottom Copper.GBR, Proyecto_PCB - CADCAM Bottom Silk Screen.GBR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]
2024-05-27 se modifico el potenciometro
    [Proyecto_PCB - CADCAM Bottom Assembly.GBR, Proyecto_PCB - CADCAM Bottom Copper.GBR, Proyecto_PCB - CADCAM Bottom Silk Screen.GBR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]
2024-06-17 Se realizo placa para regulacion de señales
    [PlacaMaestro4 - CADCAM Bottom Solder Resist.GBR, PlacaMaestro4 - CADCAM Top Assembly.GBR, PlacaMaestro4 - CADCAM Top Copper.GBR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]
2024-07-22 modificaciones en los pines de habilitación del 4051
    [PlacaMaestro4 - CADCAM Bottom Copper.GBR, PlacaMaestro4BOTTOM - CADCAM Bottom Copper.GBR, PlacaMaestro4Botton2 - CADCAM Bottom Copper.GBR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]
2026-03-24 Revise README with project details and objectives
    Updated the README to provide a comprehensive overview of the automation system for flexographic printing machines, including project description, objectives, system architecture, main functionalitie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
